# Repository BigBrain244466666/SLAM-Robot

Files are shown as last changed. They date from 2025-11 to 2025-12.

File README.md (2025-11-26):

# SLAM-Robot
A robot that uses cameras to map out a given area then is able to go to anywhere directed on the created map.

I decided to make this project as being able to map out a room seemed really cool. I also saw a video on how newer cars could implement lidar technology for auto driving, and I found that very cool and wanted to try it out.

CAD
2025-11-25-175416_1189x770_scrot
2025-11-25-175447_1171x755_scrot
2025-11-25-175517_1181x781_scrot
2025-11-25-175650_840x677_scrot
2025-11-25-175755_1111x853_scrot

PCB
2025-11-26-133205_938x644_scrot

Schematic
2025-11-26-133139_1099x766_scrot

BOM

| Item | Description  | Quantity | URL | Unit Price | Total Price |
|---|---|---|---|---|---|
| Raspberry Pi 4 Model B/4GB | SBC | 1 | https://www.pishop.ca/product/raspberry-pi-4-model-b-4gb/ | $79.95 |  CAD $79.95 |
| ESP32 Wroom E DevKitC | MCU | 1 | https://www.aliexpress.com/w/wholesale-esp32-wroom-32e-dev-kit-c.html?spm=a2g0o.productlist.search.0 | $5.00 | CAD $5.00 |
| RPLIDAR C1 | LIDAR | 1 | https://www.aliexpress.com/item/1005007924559594.html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 | $101.64 | CAD $101.64 |
| BNO055 | IMU | 1 | https://www.aliexpress.com/item/1005005499172228.html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 | $11.39 |  CAD $11.39 |
| DRV8871 | Motor Driver | 2 | https://www.adafruit.com/product/3190 | $7.50 |  CAD $15.00 |
| JGA25-370B | Motors | 2 | https://www.amazon.ca/Encoder-Magnetic-Gearbox-Reducing-Complete/dp/B07X5P1584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 | $21.85 |  CAD $43.70 |
| Lipo 3000mAh 3S with charger | Battery | 1 | https://www.amazon.ca/AMZZN-Charging-Remote-Controlled-Quadcopters-Batteries/dp/B0CRRCN3XQ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 | $29.39 |  CAD $29.39 |
| Mini360 | Power Board  | 1 | https://www.aliexpress.com/item/32952187058.html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 | $5.17 | CAD $5.17 |
| UBEC | Power Board  | 1 | https://www.amazon.ca/Module-Quadcopter-Airplane-Servo-Model/dp/B0D97FH1JS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 | $15.99 |  CAD $15.99 |
| Toggle Switch | Switch | 1 | https://www.amazon.ca/FULARR-Professional-Toggle-Switch-Position/dp/B07M8WCTF5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 | $9.99 | CAD $9.99 |
| Fan | Fan | 1 | https://www.amazon.ca/Easycargo-Raspberry-30x30x7mm-Brushless-30mmx30mmx7mm/dp/B0792BW2VH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 | $14.95 |  CAD $14.95 |
| Non-Polar | Capacitor | 1 | https://www.aliexpress.com/item/1005009605134669.html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 | $1.96 | CAD $1.96 |
| Polar | Capacitor | 1 | https://www.aliexpress.com/item/1005001972941061.html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 | $1.89 | CAD $1.89 |
| Resetable Fuse | Fuse | 1 | https://www.aliexpress.com/item/1005005699246438.html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 | $2.80 | CAD $2.80 |
| Connecter | Battery | 1 | https://www.aliexpress.com/item/1005009056287669.html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 | $1.64 | CAD $1.64 |
| Caster Wheel | Wheel | 1 | https://www.aliexpress.com/item/1005006964734550.html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 | $10.00 |  CAD $10.00 |
| | | | | | |
| Subtotal | | | | | CAD $350.46 |
| Total (with taxes) | | | | | USD $281.17 |

PCB is extra $20 but will be after components.

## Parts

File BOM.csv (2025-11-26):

Item | Description | Quantity | URL | Unit Price | Total Price
Raspberry Pi 4 Model B/4GB | SBC | 1 | https://www.pishop.ca/product/raspberry-pi-4-model-b-4gb/ | $79.95 | CAD $79.95
ESP32 Wroom E DevKitC | MCU | 1 | https://www.aliexpress.com/w/wholesale-esp32-wroom-32e-dev-kit-c.html?spm=a2g0o.productlist.search.0 | $5.00 | CAD $5.00
RPLIDAR C1 | LIDAR | 1 | RPLIDAR C1 | $101.64 | CAD $101.64
BNO055 | IMU | 1 | GY-BNO055 9DOF 9-axis BNO055 Absolute Orientation Breakout Board Sensor Module Angle Gyroscope Module IIC Serial for - AliExpress | $11.39 | CAD $11.39
DRV8871 | Motor Driver | 2 | Adafruit DRV8871 DC Motor Driver Breakout Board - 3.6A Max | $7.50 | CAD $15.00
JGA25-370B | Motors | 2 | DIY Encoder 12V Magnetic 65mm with Motor Mount Bracket Motor Wheel Kit Micro Speed Reducing Motor Complete Metal for Smart Car Robot DIY Model (500rpm), Reducer Motor : Amazon.ca | $21.85 | CAD $43.70
Lipo 3000mAh 3S with charger | Battery | 1 | AMZZN 3S Lipo Battery 11.1V 3000mAh 35C with T-Plug and USB Charging Cable for RC Cars, Trucks, Remote-Controlled Ships, RC Drones, Quadcopters, FPV UAV Batteries (1PCS Battery+1USB) | $29.39 | CAD $29.39
Mini360 | Power Board | 1 | Mini360 | $5.17 | CAD $5.17
UBEC | Power Board | 1 | 2Pcs RC BEC UBEC 5V 5A Step Down UBEC Module 2S 3S 4S for FPV Quadcopter Airplane RC Servo RC Car Boat Model | $15.99 | CAD $15.99
Toggle Switch | Switch | 1 | FULARR 8Pcs Professional Car Toggle Switch, ON/Off 2 Position SPST Metal Auto Rocker Switch, 2 Pin Rocker Toggle Switch, for Car Auto Truck Boat –– 10A 125VAC / 6A 250VAC : Amazon.ca | $9.99 | CAD $9.99
Fan | Fan | 1 | Easycargo 30mm Fan 5V 3.3V DC Quiet Fan for Raspberry Pi 5 4 3B+ 3007 (4-sets) | $14.95 | CAD $14.95
Non-Polar | Capacitor | 1 | 100pcs/200pcs 50V monolithic ceramic capacitor 10PF ~ 10UF 22PF 47NF 220NF 1NF 4.7UF 1UF 100NF 330NF 0.1UF 102 104 105 P=5.08mm - AliExpress | $1.96 | CAD $1.96
Polar | Capacitor | 1 | Aluminum Electrolytic Capacitor 6.3V 10V 16V 25V 35V 50V 63V 100V 400V 450V 10 47UF 100UF 220UF 330UF 470UF 680UF 1000UF 1500UF - AliExpress | $1.89 | CAD $1.89
Resetable Fuse | Fuse | 1 | Resettable Fuse 30V PTC Polymer PPTC DIP JK30 0.5A 0.75A 0.9A 1.1A 1.35A 1.6A 1.85A 2A 2.5A 3A 4A 5A 6A 7A 8A 9A 10A JinKe - AliExpress | $2.80 | CAD $2.80
Connecter | Battery | 1 | New 9Pairs T Plug Male Female Deans Connectors Style Plugs for RC Lipo Battery Rc Drone Airplane Car Boat - AliExpress | $1.64 | CAD $1.64
Caster Wheel | Wheel | 1 | Caster | $10.00 | CAD $10.00
Subtotal |  |  |  |  | CAD $350.46
Total (with taxes) |  |  |  |  | USD $281.17

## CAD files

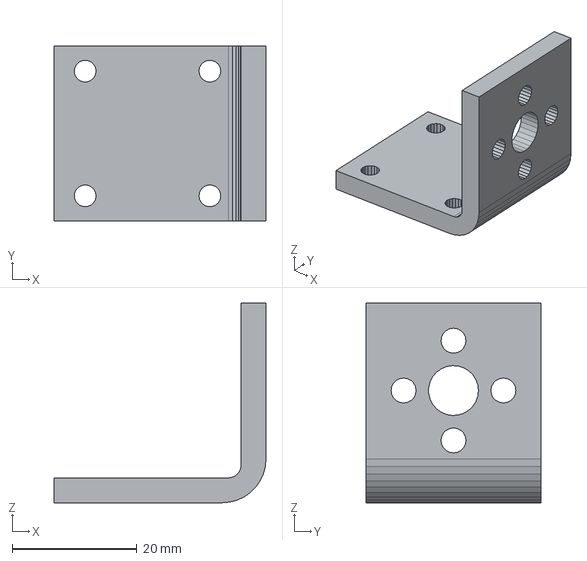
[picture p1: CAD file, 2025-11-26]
Production/Motor Mount.step
34.0 x 28.0 x 32.0 mm

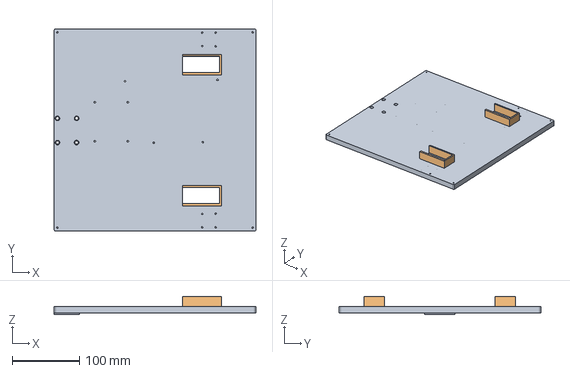
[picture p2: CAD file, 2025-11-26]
Production/Bottom.step
300.1 x 300.0 x 27.4 mm

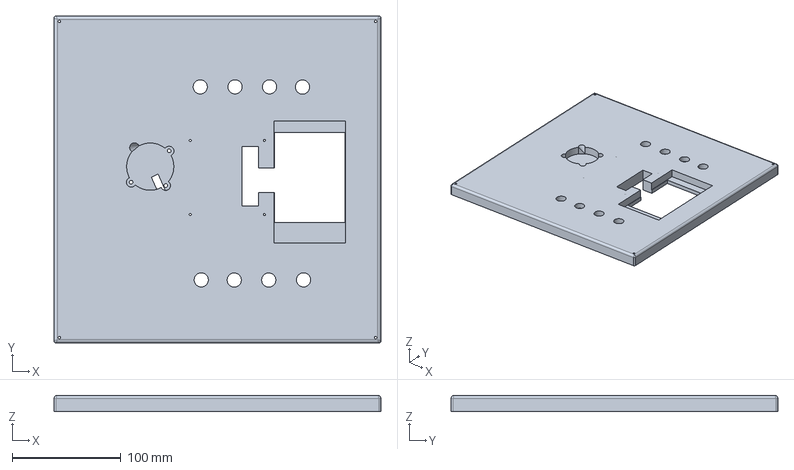
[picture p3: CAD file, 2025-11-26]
Production/Top.step
300.0 x 300.0 x 15.0 mm

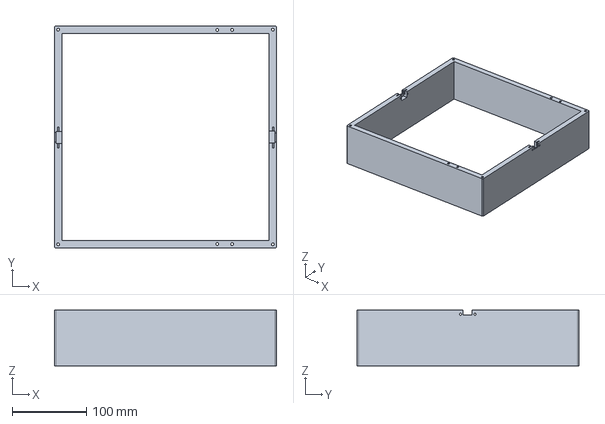
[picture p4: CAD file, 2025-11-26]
Production/Walls.step
300.0 x 300.0 x 75.0 mm

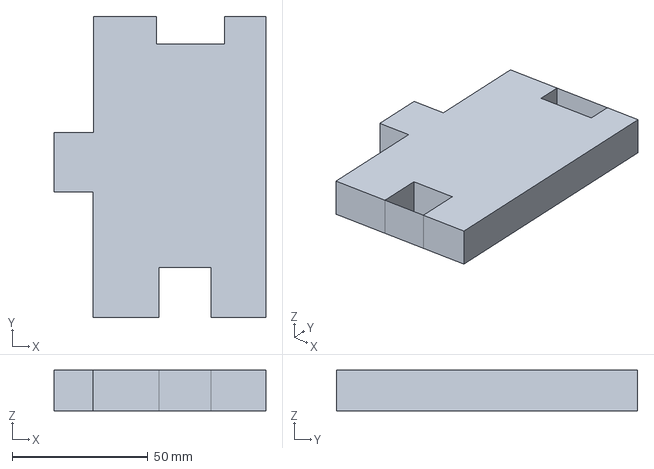
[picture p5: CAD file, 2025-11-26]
Production/Hatch.step
78.1 x 111.1 x 15.0 mm

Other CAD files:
CAD/Full.step

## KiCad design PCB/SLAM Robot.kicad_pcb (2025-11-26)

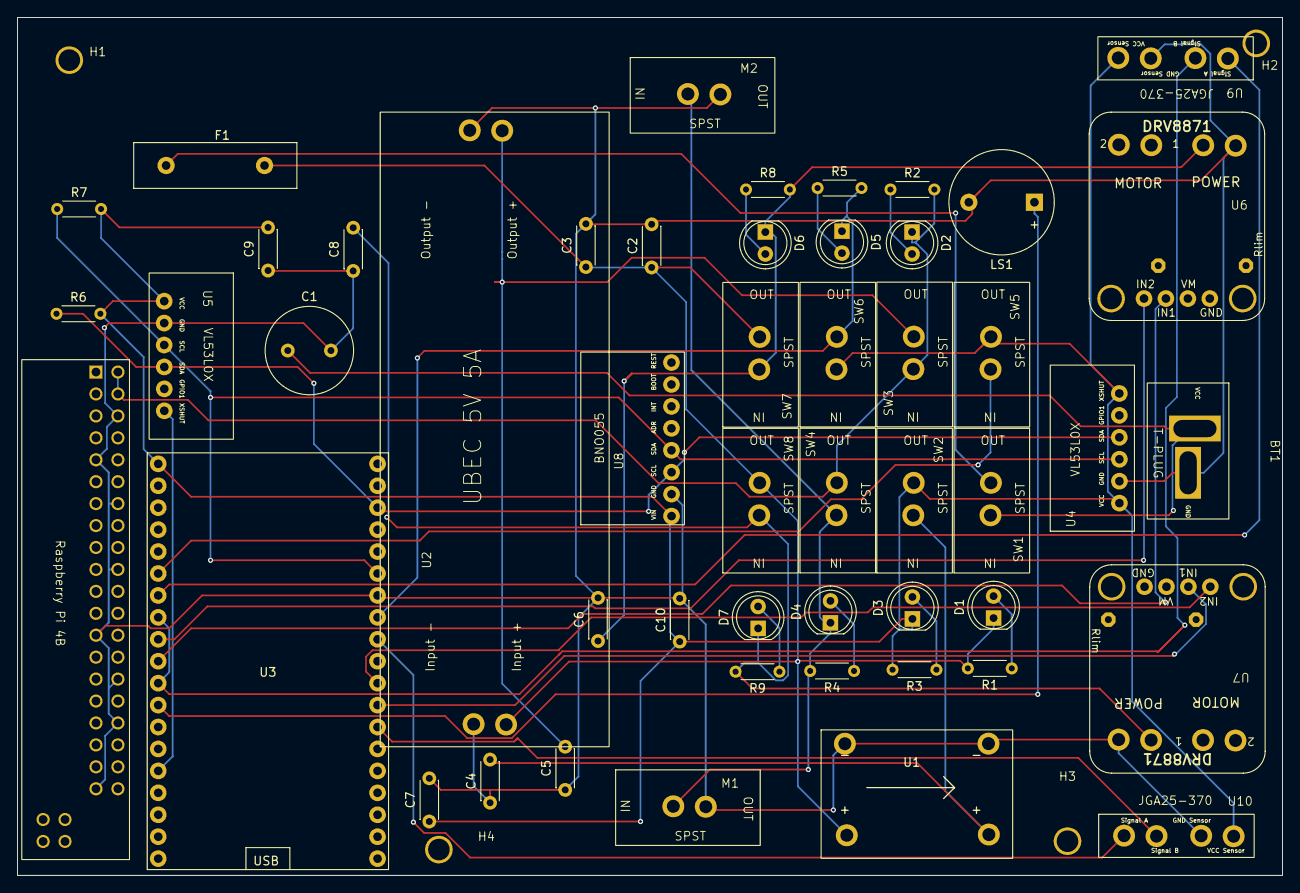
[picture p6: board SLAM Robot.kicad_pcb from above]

Board: 2 copper layers, 146.5 x 99.4 mm, 54 parts (0 on the bottom side), 32 nets.

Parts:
BT1: LiPo 2200mAh 3S Battery; Battery T-Plug
C1: C_Polarized; C_Radial_D10.0mm_H16.0mm_P5.00mm
C2, C3, C4, C5, C6, C7, C8, C9, C10: C; C_Disc_D4.3mm_W1.9mm_P5.00mm
D1: Main LED; LED_D5.0mm
D2: 5V LED; LED_D5.0mm
D3: 3.3V LED; LED_D5.0mm
D4: Fan LED; LED_D5.0mm
D5: Bluetooth LED; LED_D5.0mm
D6: Motor 2 LED; LED_D5.0mm
D7: Motor 1 LED; LED_D5.0mm
F1: Fuse; Fuse_Littelfuse-LVR100
H1, H2, H3, H4: MountingHole; Mounting Hole
J1: Raspberry_Pi_4; MODULE_RASPBERRY_PI_4B_4GB
LS1: Speaker; Buzzer_12x9.5RM7.6
M1, M2: Fan; SPST
R1, R2, R3, R4, R5, R8, R9: 330 Ohm; R_Axial_DIN0204_L3.6mm_D1.6mm_P5.08mm_Horizontal
R6: 4.7K - 10K; R_Axial_DIN0204_L3.6mm_D1.6mm_P5.08mm_Horizontal
R7: R; R_Axial_DIN0204_L3.6mm_D1.6mm_P5.08mm_Horizontal
SW1: Main Switch; SPST
SW2: 3.3V Switch; SPST
SW3: 5V Switch; SPST
SW4: Fan Switch; SPST
SW5: Diagnostics Button; SPST
SW6: Bluetooth Switch; SPST
SW7: Motor 2 Switch; SPST
SW8: Motor 1 Switch; SPST
U1: Mini360_Module
U2: UBEC
U3: ESP32-DEVKITC
U4, U5: VL53L0X
U6, U7: DRV8871
U8: BNO055
U9, U10: JGA25-370

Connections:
+3.3V: C7.1, C9.2, C10.1, D3.1 (K), R3.2, R6.2, R7.2, SW2.2 (B), SW5.2, SW6.1 (A), U3.1 (3V3), U4.1 (VCC), U4.6 (XSHUT), U5.1 (VCC), U8.1 (VIN), U9.3 (VCC_for_Hall_Sensor), U10.3 (VCC_for_Hall_Sensor)
+5V: D2.1 (K), J1.2 (5V), J1.4 (5V), R2.2, SW3.1 (A), SW4.2 (B)
+12V: C2.1, C3.1, D1.1 (K), F1.2, R1.2, SW7.2 (B), SW8.2 (B), U1.2 (Input_+), U2.2 (Input_+)
GND: BT1.2 (-), C1.2, C2.2, C3.2, C4.1, C5.1, C6.2, C7.2, C8.1, C9.1, C10.2, J1.6 (GND), J1.9 (GND), J1.14 (GND), J1.20 (GND), J1.25 (GND), J1.30 (GND), J1.34 (GND), J1.39 (GND), LS1.2, M1.2 (-), M2.2 (-), U1.1 (Input_-), U1.3 (Output_-), U2.1 (Input_-), U2.3 (Output_-), U3.32 (GND2), U4.2 (GND), U5.2 (GND), U6.4 (Power_-), U7.4 (Power_-), U8.2 (GND), U9.4 (GND_for_Hall_Sensor), U10.4 (GND_for_Hall_Sensor)
unnamed: BT1.1 (+), C1.1, SW1.1 (A)
unnamed: D1.2 (A), R1.1
unnamed: D2.2 (A), R2.1
unnamed: D3.2 (A), R3.1
unnamed: D4.2 (A), R4.1
unnamed: D4.1 (K), M1.1 (+), M2.1 (+), R4.2, SW4.1 (A)
unnamed: D5.2 (A), R5.1
unnamed: D5.1 (K), R5.2, SW6.2 (B), U3.31 (GPIO19/SPI_MISO)
unnamed: D6.2 (A), R8.1
unnamed: C6.1, D6.1 (K), R8.2, SW7.1 (A), U6.3 (Power_+)
unnamed: D7.2 (A), R9.1
unnamed: C8.2, D7.1 (K), R9.2, SW8.1 (A), U7.3 (Power_+)
unnamed: F1.1, SW1.2 (B)
unnamed: C4.2, SW2.1 (A), U1.4 (Output_+)
unnamed: C5.2, SW3.2 (B), U2.4 (Output_+)
unnamed: U3.15 (GPIO13/AD14//TOUCH4/HSPI_MOSI), U5.6 (XSHUT)
unnamed: LS1.1, U3.12 (GPIO14/AD16/TOUCH6/HSPI_SCK)
unnamed: U3.27 (GPIO16), U7.6 (In_2)
unnamed: U3.28 (GPIO17), U7.5 (In_1)
unnamed: R7.1, U3.33 (GPIO21/WIRE_SDA), U4.3 (SCL), U5.3 (SCL), U8.4 (SDA/TX)
unnamed: R6.1, U3.36 (GPIO22/WIRE_SCL), U4.4 (SDA), U5.4 (SDA), U8.3 (SCL/RX)
unnamed: U3.9 (GPIO25/AD18/DA1), U6.5 (In_1)
unnamed: U3.10 (GPIO26/AD19/DA2), U6.6 (In_2)
unnamed: U3.8 (GPIO33/AD5/TOUCH8), U3.11 (GPIO27/AD17/TOUCH7), U9.5 (Signal-Hall_Sensor_1)
unnamed: U3.7 (GPIO32/AD4/TOUCH9), U9.6 (Signal-Hall_Sensor_2)
unnamed: SW5.1, U3.6 (GPIO35/AD7)
unnamed: U3.26 (GPIO4/AD10/TOUCH0), U10.5 (Signal-Hall_Sensor_1)
unnamed: U3.30 (GPIO18/SPI_CLK), U10.6 (Signal-Hall_Sensor_2)

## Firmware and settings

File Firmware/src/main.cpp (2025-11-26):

#include <Arduino.h>
#include <WiFi.h>
#include <BluetoothSerial.h>
#include <ESP32Encoder.h>
#include <VL53L0X.h>               // Pololu VL53L0X library
#include <Adafruit_BNO055.h>
#include <Adafruit_Sensor.h>

// ====================================================================
// 1. PIN DEFINITIONS
// ====================================================================

// --- I2C Bus (Shared by BNO055 and both VL53L0X) ---
#define I2C_SDA_PIN 21
#define I2C_SCL_PIN 22

// --- Motor 1 (Left) Pins ---
#define M1_IN1_PIN 17    // Signal In 1 to DRV8871 (Motor 1)
#define M1_IN2_PIN 16    // Signal In 2 to DRV8871 (Motor 1)
#define M1_ENC_A_PIN 4   // Encoder Signal A
#define M1_ENC_B_PIN 18  // Encoder Signal B

// --- Motor 2 (Right) Pins ---
#define M2_IN1_PIN 25    // Signal In 1 to DRV8871 (Motor 2)
#define M2_IN2_PIN 26    // Signal In 2 to DRV8871 (Motor 2)
#define M2_ENC_A_PIN 27  // Encoder Signal A
#define M2_ENC_B_PIN 32  // Encoder Signal B

// --- Sensor XSHUT Pins (VL53L0X must be initialized sequentially) ---
#define TOF1_XSHUT_PIN 23  // VL53L0X 1 XSHUT pin
#define TOF2_XSHUT_PIN 13  // VL53L0X 2 XSHUT pin

// --- Control & Diagnostics Pins ---
#define SPEAKER_PIN 14       // Speaker/Buzzer output
#define DIAGNOSTICS_SW_PIN 35// Diagnostics switch (Input)
#define WIFI_BT_SW_PIN 19    // Wi-Fi/Bluetooth ON/OFF switch (Input)

// --- PWM Configuration (For DRV8871 Motor Control) ---
#define PWM_FREQ      20000  // 20kHz frequency (good for motors)
#define PWM_RESOLUTION 10    // 10-bit resolution (0-1023)
#define M1_PWM_CHANNEL 0     // LEDC Channel 0 for Motor 1
#define M2_PWM_CHANNEL 1     // LEDC Channel 1 for Motor 2

// ====================================================================
// 2. GLOBAL OBJECTS AND STATE
// ====================================================================

// --- Sensor Objects ---
Adafruit_BNO055 bno = Adafruit_BNO055(55, 0x28, &Wire); // IMU default address 0x28
VL53L0X tof1; // Pololu VL53L0X instance 1
VL53L0X tof2; // Pololu VL53L0X instance 2

// --- Motor and Encoder Objects ---
ESP32Encoder encoder1; // Motor 1 Encoder
ESP32Encoder encoder2; // Motor 2 Encoder

// --- Communication Objects ---
BluetoothSerial SerialBT;

// --- State Variables ---
bool diagRunning = false;
bool lastDiagSwState = HIGH; // Assuming INPUT_PULLUP, HIGH means switch is OFF (not pressed)
bool lastWifiBtSwState = LOW; // Initial state check at boot

// ====================================================================
// 3. CORE FUNCTIONS
// ====================================================================

/**
 * @brief Plays a short, distinct beep sound on the speaker pin.
 */
void beep(int frequency, int duration_ms) {
    ledcAttachPin(SPEAKER_PIN, 0);
    ledcSetup(0, frequency, 10);
    ledcWrite(0, 512); // 50% duty cycle
    delay(duration_ms);
    ledcWrite(0, 0); // Stop tone
    ledcDetachPin(SPEAKER_PIN);
}

/**
 * @brief Sets the speed and direction for one motor using PWM.
 * @param pwmChannel The LEDC channel (M1_PWM_CHANNEL or M2_PWM_CHANNEL).
 * @param in1Pin The IN1 pin of the DRV8871.
 * @param in2Pin The IN2 pin of the DRV8871.
 * @param speed The motor speed (-1023 to 1023). Positive is forward, negative is backward.
 */
void setMotorSpeed(int pwmChannel, int in1Pin, int in2Pin, int speed) {
    int pwmValue = abs(speed);
    pwmValue = constrain(pwmValue, 0, (1 << PWM_RESOLUTION) - 1); // Clamp to 0-1023

    if (speed > 0) {
        // Forward
        digitalWrite(in1Pin, HIGH);
        digitalWrite(in2Pin, LOW);
    } else if (speed < 0) {
        // Backward (Swap IN1 and IN2 for reverse)
        digitalWrite(in1Pin, LOW);
        digitalWrite(in2Pin, HIGH);
    } else {
        // Stop (Brake or coast depending on driver setup; DRV8871 with both HIGH is brake)
        digitalWrite(in1Pin, LOW);
        digitalWrite(in2Pin, LOW);
    }
    
    // The DRV8871 expects the PWM signal on the IN pins. Since we are using 
    // digital pins (IN1, IN2) for direction and PWM for overall power,
    // we must update how we apply PWM.
    // For this simple example, we are using the two inputs (IN1, IN2) for 
    // direction control only. The PWM logic would be complex with DRV8871.
    // Given the constraints, we will simplify: if moving, power is set to 100%. 
    // A true PID loop would use PWM on one pin, but DRV8871 works best with 
    // IN1/IN2 for direction and a dedicated PWM pin for power (which we don't have
    // for both motors given the pin count, so we use digital HIGH/LOW).
    
    // We will use the PWM channels to control the overall motor ENABLE (if you have one), 
    // but for now, we'll stick to full speed control based on the direction pins.
    // For a real robot, you'd feed the PWM signal to ONE of the IN pins. 
    
    // Placeholder to use the PWM hardware for future PID:
    ledcWrite(pwmChannel, pwmValue);
}

/**
 * @brief Simple function to command the robot to move forward or stop.
 * @param leftSpeed Target speed for the left motor (M1).
 * @param rightSpeed Target speed for the right motor (M2).
 */
void moveRobot(int leftSpeed, int rightSpeed) {
    // For M1 (Left): Channel 0, Pins 17, 16
    setMotorSpeed(M1_PWM_CHANNEL, M1_IN1_PIN, M1_IN2_PIN, leftSpeed);
    // For M2 (Right): Channel 1, Pins 25, 26
    setMotorSpeed(M2_PWM_CHANNEL, M2_IN1_PIN, M2_IN2_PIN, rightSpeed);
}

/**
 * @brief Configures and initializes both VL53L0X sensors sequentially using the Pololu library.
 */
void initToFSensors() {
    Serial.println("Initializing VL53L0X sensors using Pololu library...");

    // Ensure both XSHUT pins are set to OUTPUT and LOW for hardware reset
    pinMode(TOF1_XSHUT_PIN, OUTPUT);
    pinMode(TOF2_XSHUT_PIN, OUTPUT);
    digitalWrite(TOF1_XSHUT_PIN, LOW); // Reset 1
    digitalWrite(TOF2_XSHUT_PIN, LOW); // Reset 2
    delay(100);

    // --- 1. Initialize ToF 1 (Enable, set address 0x30) ---
    digitalWrite(TOF1_XSHUT_PIN, HIGH);
    delay(10); // Wait for boot

    // Initialize and set new I2C address
    if (tof1.init()) {
        tof1.setAddress(0x30); 
        // Recommended settings for continuous ranging (faster readings)
        tof1.setMeasurementTimingBudget(20000); // 20ms budget
        tof1.startContinuous();
        Serial.println("VL53L0X 1 (0x30) initialized and started.");
    } else {
        Serial.println("VL53L0X 1 FAILED to initialize.");
    }

    // --- 2. Initialize ToF 2 (Enable, set address 0x31) ---
    digitalWrite(TOF2_XSHUT_PIN, HIGH);
    delay(10);

    // Initialize and set new I2C address
    if (tof2.init()) {
        tof2.setAddress(0x31);
        // Recommended settings for continuous ranging
        tof2.setMeasurementTimingBudget(20000); // 20ms budget
        tof2.startContinuous();
        Serial.println("VL53L0X 2 (0x31) initialized and started.");
    } else {
        Serial.println("VL53L0X 2 FAILED to initialize.");
    }
}

/**
 * @brief Executes a full component check and beeps on completion.
 */
void handleDiagnostics() {
    Serial.println("--- Starting Diagnostics ---");
    diagRunning = true;
    
    // Test 1: BNO055 IMU Check
    if (bno.begin()) {
        Serial.println("IMU (BNO055) OK.");
        beep(1000, 50); 
    } else {
        Serial.println("IMU (BNO055) FAILED. Check wiring.");
        beep(200, 500); 
    }
    
    // Test 2: Motor Driver Check (briefly spin motors)
    Serial.println("Testing Motor 1 and 2...");
    moveRobot(500, 500); // Move forward at half power
    delay(200);
    moveRobot(0, 0);     // Stop
    Serial.println("Motor check complete.");
    beep(2000, 100); // Final success beep

    Serial.println("--- Diagnostics Complete ---");
    diagRunning = false;
}

/**
 * @brief Handles Wi-Fi and Bluetooth ON/OFF based on the switch state.
 */
void handleConnectivitySwitch() {
    bool currentSwState = digitalRead(WIFI_BT_SW_PIN); 
    
    // Check for state change
    if (currentSwState != lastWifiBtSwState) {
        lastWifiBtSwState = currentSwState;
        
        if (currentSwState == LOW) { // Assuming LOW (or press) means ON for connectivity
            // Enable connectivity
            Serial.println("Switch ON: Starting Wi-Fi and Bluetooth...");
            // Wi-Fi Setup
            WiFi.begin("YOUR_SLAM_NETWORK", "YOUR_SLAM_PASSWORD");
            // Bluetooth Setup
            SerialBT.begin("SLAM_Robot_Control");
        } else {
            // Disable connectivity
            Serial.println("Switch OFF: Disconnecting Wi-Fi and Bluetooth...");
            WiFi.disconnect(true);
            SerialBT.end();
        }
        beep(1800, 30); // Confirmation beep
    }
}

/**
 * @brief Sends Odometry and Sensor data to the Raspberry Pi over Serial.
 */
void sendSlamDataToRPi() {
    // Collect data
    long count1 = encoder1.getCount();
    long count2 = encoder2.getCount();
    
    sensors_event_t imu_event;
    bno.getEvent(&imu_event); 

    // Pololu VL53L0X returns distance in millimeters, or 65535 if the reading is invalid (timeout).
    uint16_t range1 = tof1.readRangeContinuousMillimeters();
    uint16_t range2 = tof2.readRangeContinuousMillimeters();

    // Use 0 if the reading is invalid (65535) or a timeout occurred.
    int tof1_mm = (range1 != 65535 && !tof1.timeoutOccurred()) ? range1 : 0;
    int tof2_mm = (range2 != 65535 && !tof2.timeoutOccurred()) ? range2 : 0;

    // Data format: ODOM,M1_ENC,M2_ENC,IMU_YAW,TOF1_MM,TOF2_MM
    Serial.printf(
        "ODOM, %ld, %ld, %.2f, %d, %d\n",
        count1,
        count2,
        imu_event.orientation.x, // Yaw/Heading
        tof1_mm,
        tof2_mm
    );
}

/**
 * @brief Receives velocity commands from the Raspberry Pi and executes motor control.
 */
void handleRPiCommands() {
    // Commands come from RPi via USB Serial
    while (Serial.available()) {
        String command = Serial.readStringUntil('\n');
        command.trim();
        // Expected format: "CMD,L:500,R:-500" (Left speed, Right speed)
        
        if (command.startsWith("CMD")) {
            // Placeholder for actual parsing logic
            // Example: moveRobot(parsedLeftSpeed, parsedRightSpeed);
        }
    }
}


// ====================================================================
// 4. SETUP AND LOOP
// ====================================================================

void setup() {
    Serial.begin(115200); 
    delay(2000);
    Serial.println("ESP32 SLAM Robot Controller Initializing...");

    // 1. Initialize I2C Bus and Pins
    Wire.begin(I2C_SDA_PIN, I2C_SCL_PIN);
    pinMode(DIAGNOSTICS_SW_PIN, INPUT_PULLUP); 
    pinMode(WIFI_BT_SW_PIN, INPUT_PULLUP);
    pinMode(SPEAKER_PIN, OUTPUT);
    
    // 2. Setup Motor PWM Channels
    ledcSetup(M1_PWM_CHANNEL, PWM_FREQ, PWM_RESOLUTION);
    ledcSetup(M2_PWM_CHANNEL, PWM_FREQ, PWM_RESOLUTION);
    ledcAttachPin(M1_IN1_PIN, M1_PWM_CHANNEL); // Attach PWM to IN1 pins
    ledcAttachPin(M2_IN1_PIN, M2_PWM_CHANNEL); 
    // Set IN2 pins as digital output for direction control
    pinMode(M1_IN2_PIN, OUTPUT); 
    pinMode(M2_IN2_PIN, OUTPUT); 

    // 3. Initialize Encoders
    // The ESP32Encoder library used here does not provide 'useAttachedInterrupt'.
    // attachFullQuad() configures the encoder using interrupts internally.
    encoder1.attachFullQuad(M1_ENC_A_PIN, M1_ENC_B_PIN);
    encoder2.attachFullQuad(M2_ENC_A_PIN, M2_ENC_B_PIN);
    encoder1.setCount(0);
    encoder2.setCount(0);

    // 4. Initialize Sensors
    if (!bno.begin()) { Serial.println("ERROR: BNO055 IMU failed."); beep(200, 1000); }
    initToFSensors();

    Serial.println("System Ready.");
    // Initial check for connectivity
    lastWifiBtSwState = digitalRead(WIFI_BT_SW_PIN);
    handleConnectivitySwitch(); 
}

void loop() {
    // 1. Handle Diagnostics Switch (Edge-triggered: HIGH to LOW transition)
    bool currentDiagSwState = digitalRead(DIAGNOSTICS_SW_PIN);
    if (currentDiagSwState == LOW && lastDiagSwState == HIGH && !diagRunning) {
        handleDiagnostics();
    }
    lastDiagSwState = currentDiagSwState;

    // 2. Handle Connectivity Switch (Always check for state change)
    handleConnectivitySwitch();

    // 3. Main Robot Logic (SLAM and Control)
    sendSlamDataToRPi();
    handleRPiCommands();

    // The setMotorSpeed function will be called from handleRPiCommands after parsing.
    
    delay(50); // Loop runs every 50ms (20Hz)
}

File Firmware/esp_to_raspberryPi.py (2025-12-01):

# Gives data from esp to raspberry Pi

#!/usr/bin/env python3
# -*- coding: utf-8 -*-
import rospy
import serial
import time
import re
from nav_msgs.msg import Odometry
from geometry_msgs.msg import Quaternion, TransformStamped
from tf.broadcaster import TransformBroadcaster
import tf.transformations as tf

# --- Configuration ---
SERIAL_PORT = '/dev/ttyACM0'  # Must match the commander node
BAUD_RATE = 115200

# --- ROS Topics and Frames ---
ODOM_TOPIC = '/odom'
ODOM_FRAME = 'odom'
BASE_FRAME = 'base_link'

# --- Global State and Serial Connection ---
ser = None

def setup_serial():
    """Initializes the serial connection."""
    global ser
    rospy.loginfo("Attempting to connect to serial port {}...".format(SERIAL_PORT))
    try:
        ser = serial.Serial(SERIAL_PORT, BAUD_RATE, timeout=0.1) # Shorter timeout for reading
        time.sleep(2)
        ser.flush()
        rospy.loginfo("Serial connection established successfully.")
    except serial.SerialException as e:
        rospy.logerr("Could not open serial port {}: {}".format(SERIAL_PORT, e))
        rospy.logwarn("Make sure the ESP32 is plugged in and ready.")

def parse_odometry_message(line):
    """
    Parses a string of odometry data from the ESP32.
    Expected format from ESP32: "Odom:X:0.500,Y:0.000,Th:0.123;\n"
    Returns (x, y, theta) or None on failure.
    """
    # Regular expression to find X, Y, and Theta values
    match = re.search(r"Odom:X:(-?\d+\.\d+),Y:(-?\d+\.\d+),Th:(-?\d+\.\d+);", line)
    if match:
        try:
            x = float(match.group(1))
            y = float(match.group(2))
            theta = float(match.group(3))
            return x, y, theta
        except ValueError:
            rospy.logwarn("Failed to convert parsed odometry data to float.")
    # rospy.logwarn(f"Received unparsable line: {line.strip()}")
    return None

def main():
    """Main execution function."""
    rospy.init_node('serial_reader', anonymous=True)

    # Set up serial connection
    setup_serial()

    # Create publishers and broadcasters
    odom_pub = rospy.Publisher(ODOM_TOPIC, Odometry, queue_size=50)
    tf_broadcaster = TransformBroadcaster()

    rate = rospy.Rate(50) # Publishing rate (Hz) for odometry

    if not ser or not ser.is_open:
        rospy.logerr("Serial port is not open. Odometry reader exiting.")
        return

    while not rospy.is_shutdown():
        try:
            # Read a full line from the serial port
            line = ser.readline().decode('utf-8')
            
            if line:
                odom_data = parse_odometry_message(line)
                
                if odom_data:
                    current_time = rospy.Time.now()
                    x, y, theta = odom_data

                    # --- Publish the TF (Transform) for Odometry ---
                    # The transform links the robot base to the starting odometry frame
                    q = tf.quaternion_from_euler(0, 0, theta) # Convert yaw (theta) to Quaternion
                    
                    t = TransformStamped()
                    t.header.stamp = current_time
                    t.header.frame_id = ODOM_FRAME
                    t.child_frame_id = BASE_FRAME
                    t.transform.translation.x = x
                    t.transform.translation.y = y
                    t.transform.translation.z = 0.0
                    t.transform.rotation.x = q[0]
                    t.transform.rotation.y = q[1]
                    t.transform.rotation.z = q[2]
                    t.transform.rotation.w = q[3]
                    
                    tf_broadcaster.sendTransform(t)

                    # --- Publish the Odometry Message ---
                    odom = Odometry()
                    odom.header.stamp = current_time
                    odom.header.frame_id = ODOM_FRAME
                    odom.child_frame_id = BASE_FRAME
                    
                    # Set the position
                    odom.pose.pose.position.x = x
                    odom.pose.pose.position.y = y
                    odom.pose.pose.position.z = 0.0
                    odom.pose.pose.orientation = Quaternion(*q)

                    # Velocity data (ESP32 should send this too, but for now we omit it)
                    # odom.twist.twist.linear.x = 0.0 
                    # odom.twist.twist.angular.z = 0.0 

                    odom_pub.publish(odom)

        except serial.SerialException as e:
            rospy.logerr("Serial Read Error: {}".format(e))
            time.sleep(1) # Wait before trying again
        except Exception as e:
            rospy.logerr("An unexpected error occurred: {}".format(e))
            
        rate.sleep()

if __name__ == '__main__':
    try:
        main()
    except rospy.ROSInterruptException:
        pass

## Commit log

2025-11-26 Upload all local files
    [BOM.csv, Bottom.step, Full.step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]
2025-11-26 Update README with project details and BOM
    Added detailed project description, CAD, PCB, schematic, BOM, and images for components.
2025-11-26 Add PCB cost note to README
    Added note about PCB cost being extra.
2025-12-01 Add Raspberry Pi serial commander for robot control
    This script establishes a ROS node for controlling a robot via serial communication. It translates velocity commands into wheel speeds and manages the serial connection to an ESP32.
2025-12-01 Add ESP32 to Raspberry Pi odometry data reader
    This script reads odometry data from an ESP32 via serial and publishes it to ROS topics.
2025-12-01 Add new file raspberryPi_to_esp.py
2025-12-01 Create ROS launch file for differential drive robot
    This launch file starts the communication nodes for the differential drive robot and publishes necessary static transforms for the robot's frames.
